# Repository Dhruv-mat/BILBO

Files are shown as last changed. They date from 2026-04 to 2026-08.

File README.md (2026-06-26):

## Overview

This is a custom drone I’ve been working on where I designed pretty much the entire frame from scratch instead of using a standard one.

The idea was to build something that can actually handle onboard compute and not just be a basic RC drone. Initially I was planning to use a Raspberry Pi + OAK-D Lite for perception since it kind of does everything in one go, but that didn’t really work out because of availability and cost, so I had to change things a bit.

Right now the plan is to use a RPI + RPI AI HAT with a normal RGB camera for detection and a TF-Luna LiDAR for distance. It’s definitely not as clean as the OAK-D setup, and I’m not 100% sure how well it’ll perform yet, but it should be good enough if I can get the software side working properly.

A lot of time went into redesigning parts that didn’t work. Especially the motor mounts and arm connectors, some of the earlier versions looked fine in CAD but realistically would’ve probably failed.

The frame uses carbon fiber rods for the arms and landing gear, and 3D printed connectors to hold everything together. It’s way stronger than just printing everything, and also makes it easier to tweak later.

Right now the hardware design is mostly done in CAD, next step is printing and actually seeing if it works the way I think it will.

Right now the hardware design is mostly done in CAD, and next step is printing + assembling + testing.

This new idea of the the RGB camera + a lidar sensor was inspired by this video:
https://youtu.be/Nrzs3dQ9exw?si=6kdqJGR1x-Q6_Brh

Untitledd

Untddditfffledd

---

## Components

- Pixhawk 6C (flight controller)  
- Nvidia Jetsone Nano 2GB
- RPI CAM V2
- TF Luna
- 920KV brushless motors x4  
- 20A / 30A ESCs x4  
- Carbon fiber rods (1.4 cm diameter)  
- 4S LiPo battery
- GPS MODULE
- Telemtry Kit

### Hardware

- M3 screws (10mm, 16mm, 20mm)  
- M4 screws (used for locking arms)  
- M3 female standoffs  
- M4 inserts  
- Nuts and washers  

---

## 3D Printed Parts

You’ll need to print:

- Bottom plate (main frame)  
- Middle plate (for Pixhawk mounting)  
- Top plate (for Raspberry Pi)  
- Arm connectors (holds carbon rods)  
- Motor mounts (final version is reinforced)  
- Landing gear mounts + joints  
- OAK-D Lite holder  
- Raspberry Pi holder  

---

## Assembly

Start with the base plate.



Attach the arm connectors onto the base using M3 screws (I used ~16mm mostly). Make sure these are tight because this is where all the stress goes.



Now insert the carbon fiber rods into the connectors. The fit should already be tight, but I added a side hole so you can pass an M4 screw through and lock it in place.



---

Next is the motor side.
Each arm ends in a motor mount. My first design didn’t work because the alignment was off and there wasn’t enough support, so I switched to a more reinforced design (kind of like a wishbone support).
Attach the motors using standard screws and route the wires back toward the center.



---

Now for the frame stack.
Use M3 standoffs to mount the middle plate above the base. This is where the Pixhawk goes.
Then add another set of standoffs and attach the top plate. The Raspberry Pi sits on top.



---

Landing gear goes on the bottom.
It uses the same carbon rods with angled connectors. I didn’t want it to be completely rigid, so there’s a bit of flexibility to absorb impact when landing.



---

For perception, mount the RGB camera on the front using a custom holder, slightly angled forward.
The TF-Luna LiDAR is mounted alongside it to provide distance measurements.



Untddditfffledd

---

## Electronics Overview

Here is the full system schematic for the drone, including power distribution, flight controller connections, and companion computer setup.


---

## Frame Stress Testing

Also I ran an a basic static stress test on the frame to get a rough idea of how it behaves under load. applied upward forces at the motor mounts to simulate thrust and checked deformation and stress distribution across the arms and connectors. Most of the stress seems to concentrate near the joints and motor mounts which i kinda expected, but nothing looks completely crazy or like it’ll instantly fail. deformation is pretty small overall, so structurally it seems fine for now, although this is still a simplified test and real-world vibrations and impacts aren’t accounted for yet.

WhatsApp Image 2026-04-07 at 09 31 21

WhatsApp Image 2026-04-07 at 09 31 22

---
## Notes

This took way more iteration than expected.
A lot of designs had to be scrapped after realizing they wouldn’t actually work under load. The motor mount especially had to be redone after noticing alignment issues.
Switching to carbon fiber rods instead of fully printed arms made a big difference. It’s way stronger and lighter.
Still a lot left to do but the structure is finally in a place where I can start building it properly.

## Bill of Materials (BOM)

| Part | Quantity | Price (USD) |
|---|---|---|
| Propellers (Pair) | 2 | $2.02 |
|3d prinintg | 1| 35$
| RC Receiver | 1 | $45.78 |
| Telemetry Kit | 1 | $77.11 |
| GPS Module (u-blox) | 1 | $40 |
| ESC (30A BLHeli) | 4 | $38.55 |
| 920KV Brushless Motors | 4 | $31 |
| RPI AI HAT 13TOPS | 1 | $70 |
| Pixhawk 6C | 1 | $360 |
| Rpi Cam V2 | 1 | $18 |
| TF Luna | 1 | $22 |
| LiPo Battery 3S 5200mAh | 1 | $35 |
| Power Distribution Board (PDB) | 1 | $5|
| Holybro PM02 Power Module | 1 | $27|
| Carbon Fiber Rod (25cm) | 1 | $22 |
| Carbon Fiber Tube (Landing Legs) | 1 | $11.7 |
| M3 Female Inserts | 20 | $1 |
| M4 Female Inserts | 20 | $1|
| M3 Screw Set | 1 | $3 |
| M4 Screw Set | 1 | $3 |

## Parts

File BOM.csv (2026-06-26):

Parts | Quantitiy | Total Price USD | Owned
Popellors | 2 | 2.02 | yes
RC Reciver & Transmitter | 1 | 45 | yes
Telemetry Kit | 1 | 77 | yes
GPS module | 1 | 40 | yes
ESC (30A BHeli) | 4 | 38 | yes
920Kv motor | 4 | 31 | no
RPI AI HAT | 1 | 70 | no
Rpi cam V2 | 1 | 18 | no
TF Luna | 1 | 22 | no
Pixhawk 6c | 1 | 360 | yes
LiPO battery 3s 5200mah | 1 | 35 | yes
PDB | 1 | 5 | yes
PMO2 Module | 1 | 27 | no
3d printing | 1 | 35 | no
carbon fiber rod (25cm) | 2 | 22 | no
carbon fiber rod | 1 | 11 | no
M3 Female Insert | 20 | 1 | yes
M4 Female Insert | 20 | 1 | yes
M3 Screws set | 1 | 1 | yes
M4 Screws set | 1 | 1 | yes

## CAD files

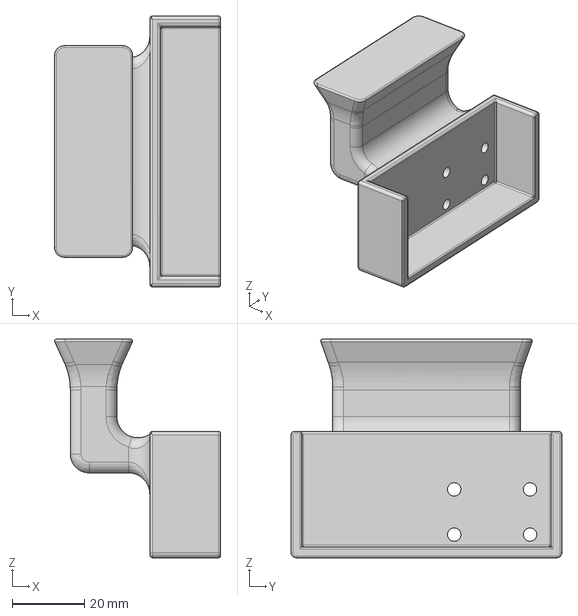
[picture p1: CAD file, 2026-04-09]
BILBO 3D files/sensor holder.step
46.0 x 75.0 x 60.5 mm

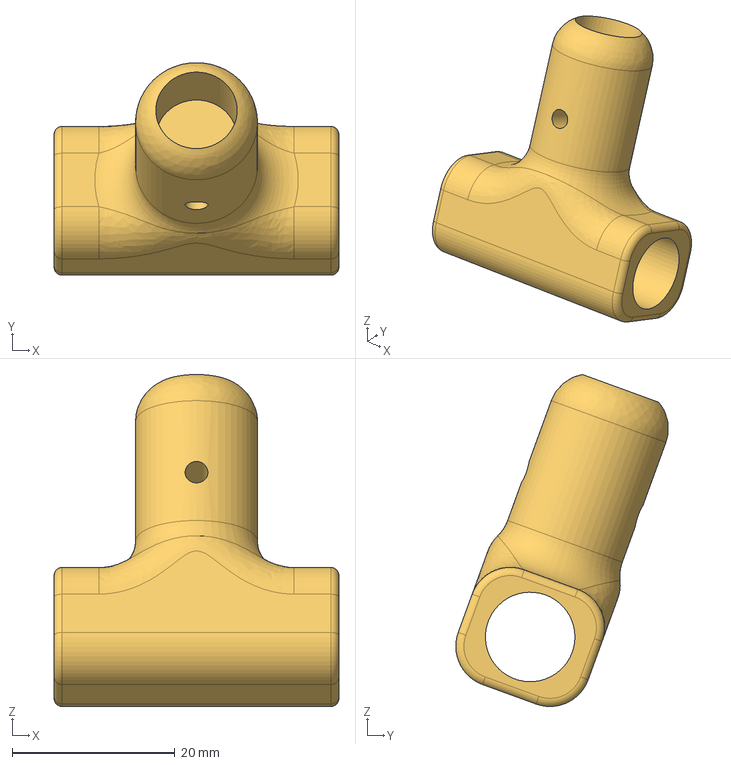
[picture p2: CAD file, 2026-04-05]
BILBO 3D files/BILBO landing gear bracket.step
35.0 x 26.1 x 40.8 mm

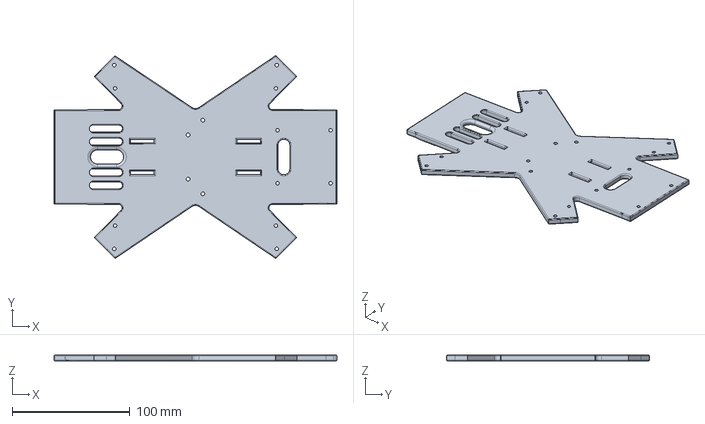
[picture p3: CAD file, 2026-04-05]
BILBO 3D files/BILBO bottom frame.step
240.0 x 172.0 x 5.00 mm

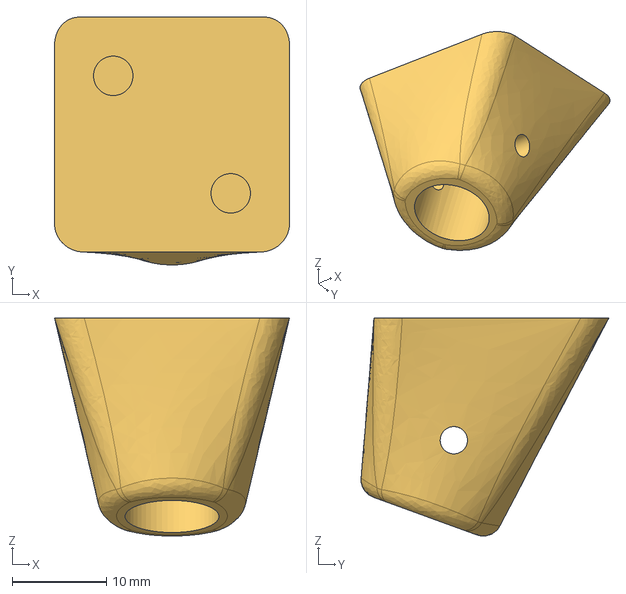
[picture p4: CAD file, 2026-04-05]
BILBO 3D files/BILBO landing gear R.step
25.0 x 26.4 x 23.2 mm

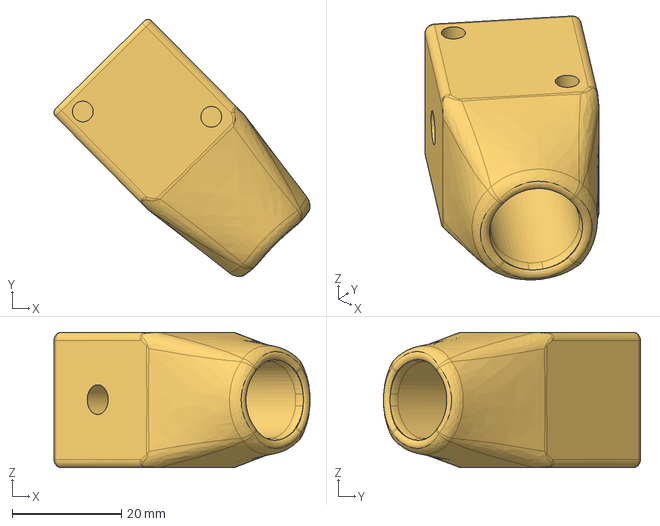
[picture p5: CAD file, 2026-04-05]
BILBO 3D files/BILBO arm connector L.step
47.0 x 47.2 x 24.8 mm

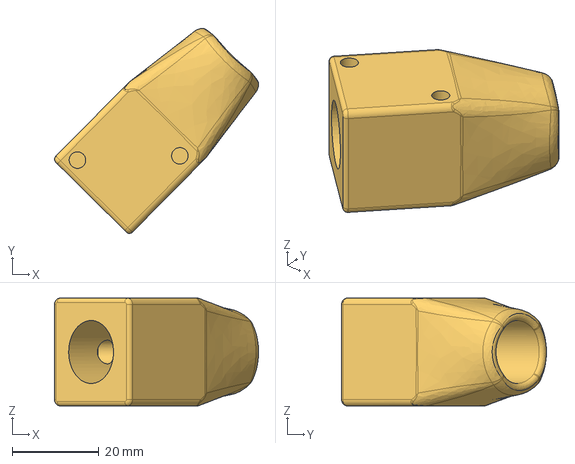
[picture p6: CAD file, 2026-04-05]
BILBO 3D files/BILBO arm connector R.step
47.0 x 47.1 x 24.8 mm

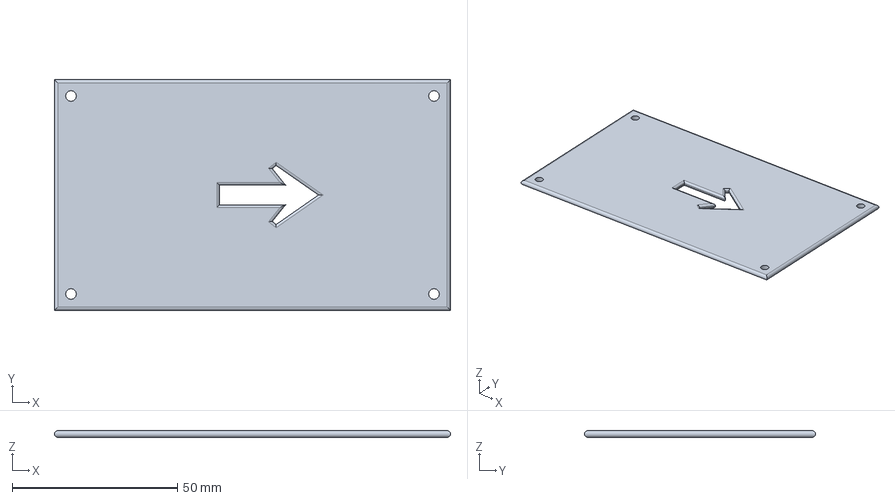
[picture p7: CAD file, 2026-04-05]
BILBO 3D files/BILBO pixhawk mount.step
120.0 x 70.0 x 2.00 mm

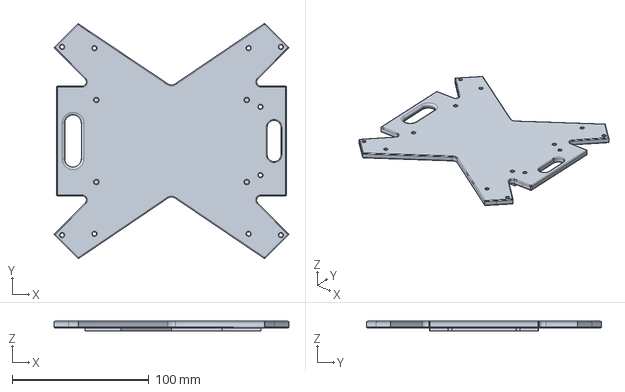
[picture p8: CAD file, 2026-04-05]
BILBO 3D files/BILBO top frame.step
171.8 x 172.0 x 7.00 mm

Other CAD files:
BILBO 3D files/BILBO landing gear L.step
BILBO 3D files/BILBO THE COMPLETE DRONE.f3d

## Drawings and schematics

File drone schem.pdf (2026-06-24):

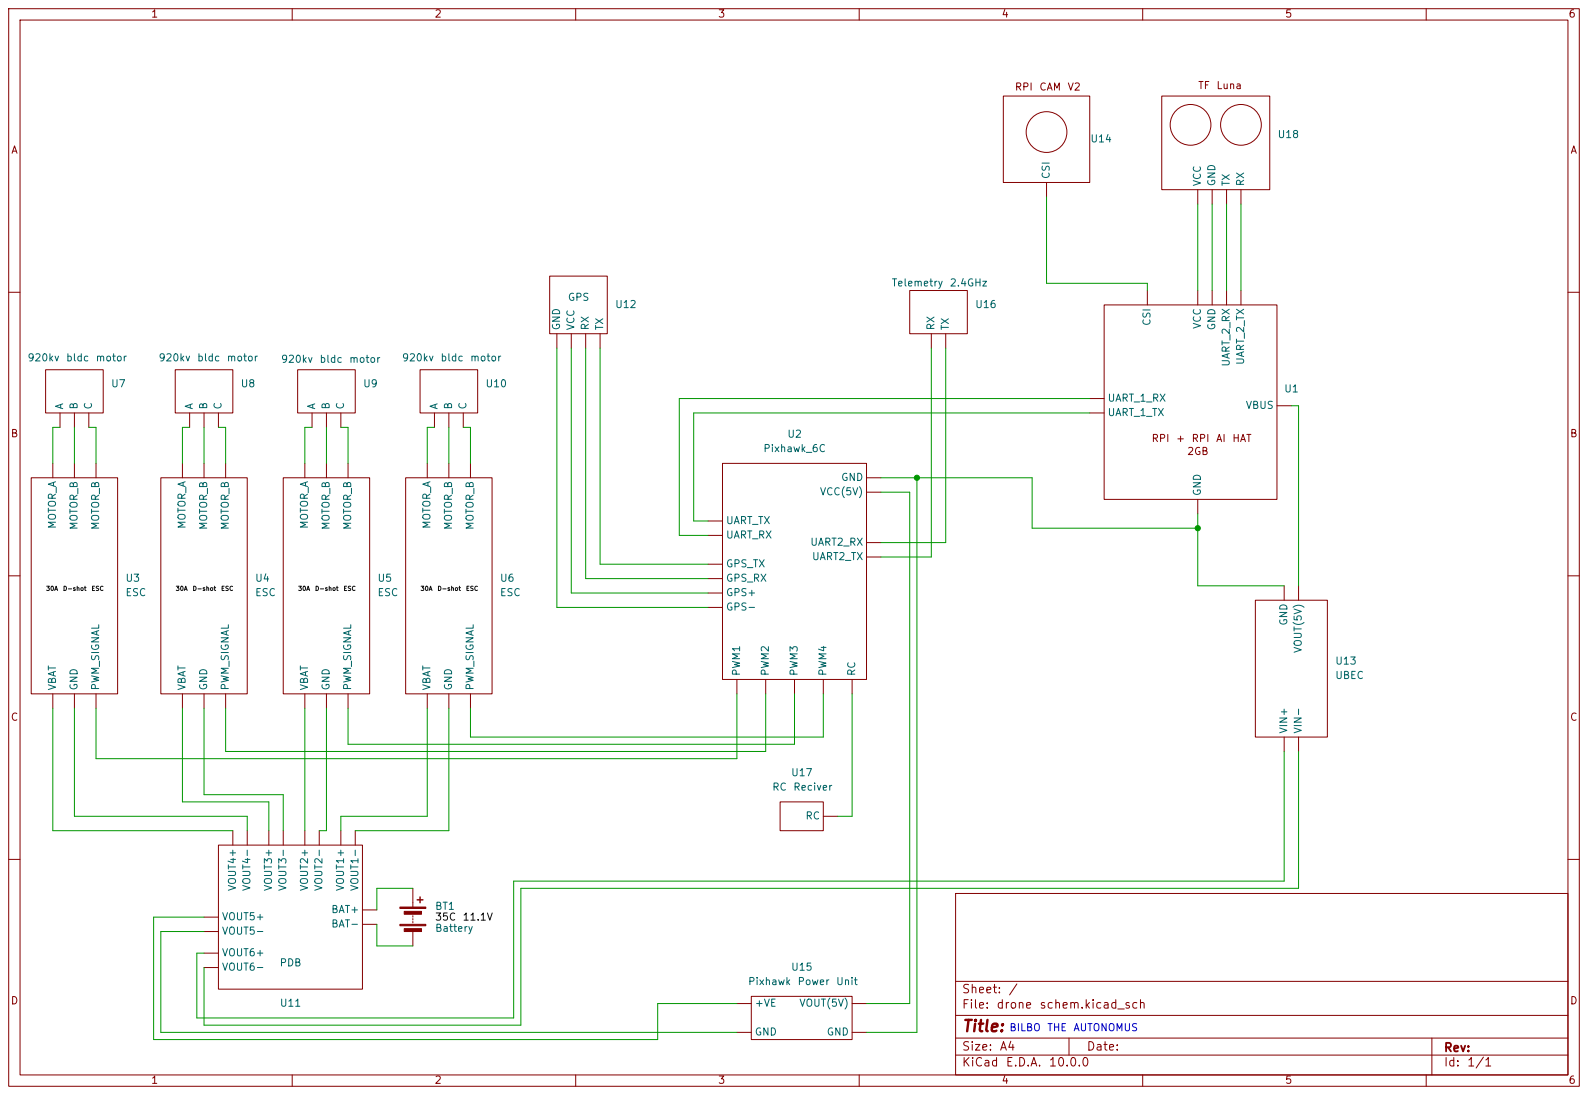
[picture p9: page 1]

VOUT(5V) GND U15 Pixhawk Power Unit RC U17 RC Reciver

Size: A4 | Rev:
KiCad E.D.A. 10.0.0 | Id: 1/1

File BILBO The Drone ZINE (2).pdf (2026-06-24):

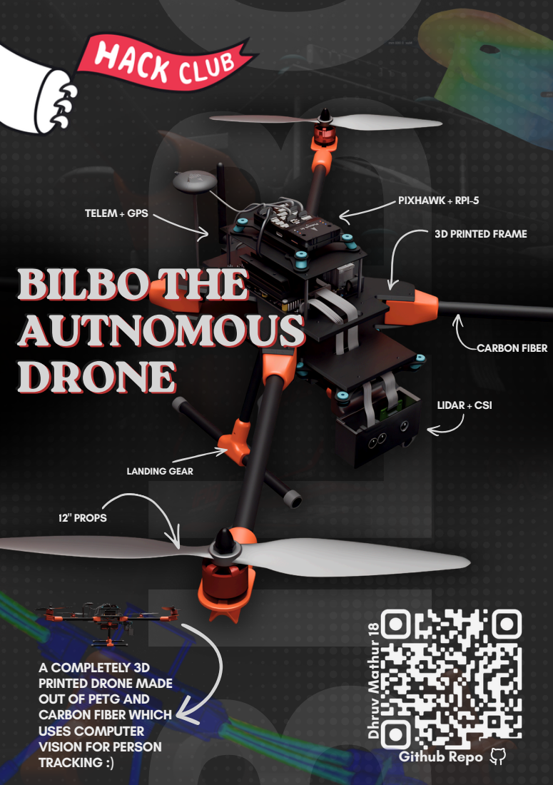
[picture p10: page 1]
BBIILLBBOOTTHHEE AAUUTTNNOOMMOOUUSS DRONE; BILBO THE AUTNOMOUS DRONE; LIDAR + CSI; 3D PRINTED FRAME; Github Repo; PIXHAWK + RPI-5; 12" PROPS; TELEM + GPS; LANDING GEAR; CARBON FIBER

A COMPLETELY 3D
PRINTED DRONE MADE
OUT OF PETG AND
CARBON FIBER WHICH
USES COMPUTER
VISION FOR PERSON
TRACKING :)

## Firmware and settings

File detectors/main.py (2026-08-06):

import csv
import logging
import logging.handlers
import os
import signal
import sys
import time

import config as cfg
import camera
import controller
import drone
import led
import lidar
import tracker
from state import DroneState

_log = logging.getLogger("bilbo")

print("hi bitches")

# okay so this is basically gonna be a function that controls how much freedom the drone will hvae
OFF, YAW_ONLY, FULL = 0 ,1, 2
_ENABLE_NAMES = {OFF: "OFF", YAW_ONLY: "YAW_ONLY", FULL: "FULL"}


state = DroneState.IDLE

reacquire_count = 0
prev_enable = None
engage_armed = False      
confirm_count = 0           

lost_since = None          
last_error_x = 0.0
last_confident_track = None  
track_started = None

search_start = None
search_dir = 1.0           

last_dist = None
last_dist_t = None
jump_count = 0

vision_faults = 0

self_commanded_mode = None 
rtl_requested = False
emergency_since = None
rtl_attempts = 0
land_attempted = False

fault_latch = None
consecutive_faults = 0
_slow_tick = False          
_shutdown = False

_csv_file = None
_csv_writer = None
_last_csv_flush = 0.0
_last_status_log = 0.0



def _setup_logging(): 
    root = logging.getLogger()
    root .setLevel(getattr(logging, cfg.LOG_LEVEL, logging.INFO))

    fmt = logging.Formatter(
        "%(asctime)s %(levelname)-7s %(name)s: %(message)s"
    )

    try:
        os.mkdir(cfg.LOG_DIR,exist_ok = True)
        handler = logging.handlers.RotatingFileHandler(
            os.path.join(cfg.LOG_DIR, "bilbo.log"),
            maxBytes=cfg.LOG_MAX_BYTES,
            backupCount=cfg.LOG_BACKUPS,
        )
        handler.setFormatter(fmt)
        root.addHandler(handler)

    except Exception:

        stream = logging.StreamHandler(sys.stderr)
        stream.setFormatter(fmt)
        root.addHandler(stream)
        root.error("file logging is not working, using stderr", exec_info = True)
        return

    if cfg.DEBUG_CONSOLE:
        stream = logging.StreamHandler(sys.stderr)
        stream.setFormatter(fmt)
        root.addHandler(stream)

CSV_COLUMNS = [
    "t", "state", "enable", "mode", "armed", "alt_m", "link_age_s",
    "rc_age_s", "vision_age_s", "n_persons", "error_x", "error_y",
    "bearing_deg", "dist_cm", "dist_age_s", "yaw_rate", "forward",
    "gate", "tick_s", "fault",

]

#-----the logging pant------------

# all of this is bieng done so i can data log and if needed change the values of that pid loop
def _open_csv():
    global _csv_file, _csv_writer
    try:
        path = os.path.join(cfg.LOG_DIR, "flight-%d.csv" % int(time.time()))
        _csv_file = open(path, "w", newline="", buffering=1024 * 64)
        _csv_writer = csv.writer(_csv_file)
        _csv_writer.writerow(CSV_COLUMNS)
        _log.info("flight log: %s", path)
    except Exception:
        _log.exception("could not open CSV flight log (sad stuffff)")
        _csv_file = None
        _csv_writer = None

def _fmt(value,spec):
    return "" if value is None else spec % value

# alright now we gotta write those csv values in some fancy prtty pretty formats 
def _write_record(record,now):
    global _last_csv_flush
    if _csv_writer is None:
        return


    # also i used chatgpt to generate this really fancy csv file (hope thats cool caue without this formatting im dead)
    try:
        _csv_writer.writerow([
            "%.3f" % now,
            record.get("state", ""),
            record.get("enable", ""),
            record.get("mode") or "",
             "%.2f" % drone.link_age(),
            "%.2f" % drone.rc_age(),
            "%.3f" % record.get("vision_age", float("inf")),
            _fmt(record.get("n_persons"), "%d"),
            "%.1f" % record.get("error_x", 0.0),
            "%.1f" % record.get("error_y", 0.0),
            "%.2f" % record.get("bearing_deg", 0.0),
            _fmt(record.get("distance_cm"), "%d"),
            _fmt(None if last_dist_t is None else distance_age(now), "%.2f"),
            "%.2f" % record.get("yaw_rate", 0.0),
            "%.3f" % record.get("forward", 0.0),
            record.get("gate", ""),
            "%.4f" % record.get("tick_s", 0.0),
            fault_latch or "",
        ])
        # till here heheheh

        if now - _last_csv_flush >= cfg.CSV_FLUSH_INTERVAL_S:
            _csv_file.flush()
            _last_csv_flush = now

    except Exception:
        _log.exception("CSV FILE DID NOT WORRKKK")


def _status(now, message, *args):
    global _last_status_log

    if now - _last_status_log < cfg.STATUS_LOG_INTERVAL_S:
        return
    _last_status_log = now
    _log.info(message, *args)

def _on_signal(signum,_frame):
    global _shutdown
    _shutdown = True
    _log.warning("signal %d received; shutting down", signum)



#----- reseting the PID LOOP PARTTTT---------

def soft_reset(keep_target = False):

    #this part helps setting the pid loops back to zero so no corrrections are pre stored

    global lost_since, reacquire_count, confirm_count, last_error_x
    global last_dist, last_dist_t, jump_count, vision_faults, track_started

    controller.reset()
    if not keep_target:
        tracker.reset()

    lost_since = 0
    reacquire_count = 0
    confirm_count = 0 
    last_error_x = 0
    last_dist = None
    last_dist_t = None
    jump_count = 0
    vision_faults = 0
    track_started = None


#------ really cool lidar logic--------

def update_dist(new_cm, now):
    if new_cm ==None:
        return

    # okay so this part is really sick, what i am trying to do here is making sure the jump in lidar is realistic and not an out of frame error
    if (last_dist is not None and abs(new_cm-last_dist) > cfg.LIDAR_MAX_JUMP_CM):
        jump_count +=1
        if jump_count < cfg.LIDAR_JUMP_CONFIRMS:
            _log.debug("rejecting range jump %d -> %d cm", last_dist, new_cm)
            return

    jump_count = 0
    last_dist = new_cm
    last_dist = now

def distance_or_none(now):

    if last_dist is None or last_dist_t is None:
        return None
    if now - last_dist > cfg.LIDAR_MAX_AGE_S:
        return None
    return last_dist


# this is just something i wanted for the csv column to see how old the lidar is, only used for debugging
def distance_age(now):
    if last_dist_t is None:
        return float("inf")
    return now - last_dist_t


#----- Writing the code to understand the RC funcs----------

def read_enable(now):
    "the 3 channel switching"
    raw = drone.get_channel(cfg.CH_ENABLE)
    if raw is None or drone.rc_age() > cfg.RC_STALE_S:
        return OFF
    if raw < cfg.SWITCH_MID_LOW_US:
        return OFF
    if raw < cfg.SWITCH_MID_HIGH_US:
        return YAW_ONLY
    return FULL

def request_mode(mode, timeout = 1.5, retries = 1):

    global _slow_tick, self_commanded_mode
    _slow_tick = True
    if drone.set_mode(mode, timeout=timeout, retries = retries):
        self_commanded_mode = mode
        return True
    return False



def enter_rtl(reason):
    global state, rtl_requested
    if state == DroneState.RTL:
        return
    _log.warning("RTL(%s)",reason)
    state = DroneState.RTL
    rtl_requested = False


def enter_emegency(reason):
    global state, emergency_since, rtl_attempts, land_attempted
    if state == DroneState.EMERGENCY:
        return
    state = DroneState.EMERGENCY
    emergency_since = None
    rtl_attempts = 0
    land_attempted = False


#------preflight checks and weird ass things--------

def _wait_for(predicate, timeout, interval=0.05, pump=None):
    deadline = time.monotonic() + timeout
    while time.monotonic() < deadline:
        if pump is not None:
            pump()
        try:
            if predicate():
                return True
        except Exception:
            _log.exception("preflight issues happended")


# this one is really important cause it checks if everything is working and fineee before the flight 

def preflight():

    led.init()
    led.selftest()

    if not drone.connect(timeout = 10.0):
        _log.error("Preflight Fail: Mavlink ain't working")
        return False

    try:
        lidar.init()
    except Exception:
        _log.error("Preflight Fail: LiDAR ain't working")
        return False
    
    valid = {'n':0}

    def lidar_healthy():
        if lidar.read_data() is not None:
            valid["n"] += 1
        return valid["n"] >= cfg.LIDAR_HEALTH_FRAMES


    if not _wait_for(lidar_healthy, timeout=3.0):
        _log.error("Preflight Fail:LiDAR gave %d/%d valid frames (%s)",
                   valid["n"], cfg.LIDAR_HEALTH_FRAMES, lidar.health())

        return False

    try:
        width, height = camera.intitalise()
    except Exception:
        _log.exception("Preflight Fail: camera did not start")
        return False

    if not _wait_for(camera.inference_alive, timeout=8.0):
        _log.error("Preflight Fail: no inference output from the IMX500")
        return False

    try:
        tracker.configure(width, height)
    except Exception:
        _log.exception("PREFLIGHT FAIL: camera geometry mismatch")
        return False


    if not _wait_for( lambda: drone.get_channel(cfg.CH_ENABLE) is not None, timeout=5.0,pump=drone.poll):
        _log.error("Preflight Fail: no RC input detected, could never switch to guided")
        return False

    _log.info("preflight OK (lidar %s, camera %s)",
              lidar.health(), camera.health())
    return True


#-----live checks--------

#so basically this part of the code is gonna keep checking if everything is still working after preflight

def run_tick(now, tick_duration):
    global state, prev_enable, engage_armed, confirm_count
    global lost_since, reacquire_count, last_error_x, last_confident_track
    global track_started, vision_faults, fault_latch
    global self_commanded_mode, rtl_requested
    global emergency_since, rtl_attempts, land_attempted
    global search_start, search_dir


    record = {
        "state": state.name, "enable": "?", "mode": None, "armed": False,
        "alt": None, "vision_age": float("inf"), "n_persons": None,
        "error_x": 0.0, "error_y": 0.0, "bearing_deg": 0.0,
        "distance_cm": None, "yaw_rate": 0.0, "forward": 0.0, "gate": "-",
        "tick_s": tick_duration,
    }


    drone.poll()
    drone.send_heartbeat()

    if not drone.link_ok():
        if fault_latch != "link":
            _log.error("MAVLink link lost (age %.1fs)", drone.link_age())
            fault_latch = "link"

        if state in (DroneState.TRACKING, DroneState.SEARCHING):
            soft_reset()
            enter_emergency("link lost")

        drone.reconnect()
        record["gate"] = "link_lost"
        return record

    if fault_latch == "link":
        _log.warning("MAVLink link restored")
        fault_latch = None

    mode = drone.get_mode()
    armed = drone.is_armed()
    alt = drone.get_relative_alt()

    enable = read_enable(now)

    previous_enable = prev_enable
    prev_enable = enable

    record["mode"] = mode
    record["armed"] = armed
    record["alt"] = alt
    record["enable"] = _ENABLE_NAMES.get(enable, "?")

    vision_ts, persons = camera.get_latest()
    vision_age = now - vision_ts

    vision_ok = persons is not None and vision_age <= cfg.VISION_MAX_AGE_S
    record["vision_age"] = vision_age
    record["n_persons"] = None if persons is None else len(persons)

    if state in (DroneState.TRACKING, DroneState.SEARCHING):
        if vision_ok:
            vision_faults = 0
        else:
            vision_faults += 1
            if vision_faults == 1:
                _log.warning(
                    "vision unhealthy: detection age %.2fs, frame age %.2fs, "
                    "persons=%s, health=%s",
                    vision_age, camera.frame_age(),
                    "None" if persons is None else len(persons),
                    camera.health(),
                )
            if vision_faults >= cfg.MAX_VISION_FAULTS:
                soft_reset()
                enter_emergency("vision stalled")


    if mode != "GUIDED":
        if self_commanded_mode is not None and mode == self_commanded_mode:
            record["gate"] = "self_" + mode.lower()
            return record

        if state != DroneState.IDLE:
            _log.info("pilot mode is %s -> IDLE", mode)
            soft_reset()
            state = DroneState.IDLE
        self_commanded_mode = None
        rtl_requested = False
        emergency_since = None
        engage_armed = False
        record["gate"] = "pilot"
        return record

    if enable == OFF:
        engage_armed = False
    elif previous_enable == OFF:
        if not engage_armed:
            _log.info("AI enable edge seen (%s)", _ENABLE_NAMES[enable])
        engage_armed = True


    if enable == OFF and state in (DroneState.TRACKING, DroneState.SEARCHING):
        _log.warning("AI disabled by RC -> READY")
        soft_reset()
        state = DroneState.READY



    if state == DroneState.IDLE:
        soft_reset()
        state = DroneState.READY
        _log.info("READY")
        drone.hover()

    elif state == DroneState.READY:
        drone.hover()

        target = tracker.select(persons) if vision_ok else None
        confirm_count = confirm_count + 1 if target is not None else 0

        alt_ok = alt is not None and alt >= cfg.MIN_TRACK_ALT_M
        target_ok = confirm_count >= cfg.TARGET_CONFIRM_FRAMES

        if engage_armed:
            if not armed:
                _status(now, "engage held: not armed")
            elif not alt_ok:
                _status(now, "engage held: altitude %s < %.1f m",
                        "unknown" if alt is None else "%.1f" % alt,
                        cfg.MIN_TRACK_ALT_M)
            elif not target_ok:
                _status(now, "engage held: target unconfirmed (%d/%d)",
                        confirm_count, cfg.TARGET_CONFIRM_FRAMES)
            else:
                soft_reset(keep_target=True)
                state = DroneState.TRACKING
                track_started = now
                last_confident_track = now
                engage_armed = False
                _log.info("TRACKING engaged (%s)", _ENABLE_NAMES[enable])








    
    




while True:

    ch6 = drone.get_channel(6)
    mode = drone.get_mode()

    if mode != "GUIDED":
        drone.stop()
        state = DroneState.IDLE
        continue

    if state == DroneState.READY:
        if ch6 is not None and ch6 > SWITCH_HIGH:
            print("Tracking enabled")
            led.led_status(effect="solid", color="blue")
            state = DroneState.TRACKING
            continue

    elif state == DroneState.TRACKING:

        persons = camera.get_people()
        target = tracker.select(persons)
        led.led_status(effect="solid", color="green")

        if target is not None:
            lost_frames = 0

        if target is None:
            lost_frames += 1

            if lost_frames >= LOST_FRAME_LIMIT:
                print("starting up searching")
                search_start_time = time.monotonic()
                state = DroneState.SEARCHING
            continue


        if last_good_distance is None:
            lock_center = CAMERA_CENTER
        else:
            lock_center = tracker.get_lock_center(last_good_distance)
        locked, error_x = tracker.is_locked(target, lock_center)

        if abs(error_x) < controller.YAW_DEADBAND:
            
            new_distance = lidar.read_data()
            if new_distance is not None:
                last_good_distance = new_distance

        controller.update(error_x, last_good_distance)

    elif state == DroneState.SEARCHING:

        print("Searching...")
        led.led_status(effect="blink", color="yellow")
        persons = camera.get_people()
        target = tracker.select(persons)

        if target is not None:
            print("Target found!")
            state = DroneState.TRACKING
            continue

        drone.move(
            yaw_rate=SEARCH_YAW_RATE
        )

        if time.monotonic() - search_start_time > SEARCH_TIMEOUT:
            state = DroneState.RTL

    elif state == DroneState.IDLE:
        led.led_status(effect="solid", color="white")
        if mode == "GUIDED":
            print("READY")
            state = DroneState.READY

        continue

    elif state == DroneState.RTL:
        print("RTL")
        led.led_status(effect="solid", color="purple")
        drone.set_mode("RTL")
        continue

    elif state == DroneState.EMERGENCY:
        drone.hover()
        led.led_status(effect="blink", color="red")
        continue

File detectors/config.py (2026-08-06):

import os

MAVLINK_DEVICE = "/dev/serial/by-id/usb-Prolific_Technology_Inc._USB-Serial_Controller_D-if00-port0"
MAVLINK_DEVICE_GLOBS = (
    "/dev/serial/by-id/*FTDI*",
    "usb-Prolific_Technology_Inc._USB-Serial_Controller_D-if00-port0",
)
MAVLINK_BAUD = 57600
LIDAR_DEVICE = "/dev/ttyAMA0"
LIDAR_BAUD = 115200

LED_DEVICE = "/dev/spidev0.0"
LED_COUNT = 25
LED_BRIGHTNESS = 0.3
LED_SPI_KHZ = 800


LOG_DIR = os.path.expanduser("~/bilbo-logs")
LOG_LEVEL = "INFO"
LOG_MAX_BYTES = 8 * 1024 * 1024
LOG_BACKUPS = 5
STATUS_LOG_INTERVAL_S = 0.5
CSV_FLUSH_INTERVAL_S = 1.0


DEBUG_CONSOLE = os.environ.get("BILBO_DEBUG_CONSOLE", "0") == "1"
DEBUG_PREVIEW = os.environ.get("BILBO_DEBUG_PREVIEW", "0") == "1"
DEBUG_DRAW = os.environ.get("BILBO_DEBUG_DRAW", "0") == "1"



TICK_HZ = 15.0
TICK_PERIOD_S = 1.0 / TICK_HZ
MIN_SETPOINT_INTERVAL_S = 1.0 / 20.0

TICK_OVERRUN_LIMIT_S = 0.5
MAX_CONSECUTIVE_FAULTS = 5

HEARTBEAT_TX_INTERVAL_S = 1.0

LINK_TIMEOUT_S = 3.0
RECONNECT_INTERVAL_S = 1.0
RC_STALE_S = 1.0
VISION_MAX_AGE_S = 0.3
MAX_VISION_FAULTS = 30  

IMAGE_WIDTH_PX = 640
IMAGE_HEIGHT_PX = 480
CAMERA_FOV_DEG = 78.0
PIXELS_PER_DEGREE = IMAGE_WIDTH_PX / CAMERA_FOV_DEG

CAMERA_IS_INVERTED = True
LIDAR_MIN_CM = 20
LIDAR_MAX_CM = 800

LIDAR_MIN_STRENGTH = 100
LIDAR_RX_BUFFER_CAP = 512
LIDAR_MAX_AGE_S = 1.0

LIDAR_MAX_JUMP_CM = 150
LIDAR_JUMP_CONFIRMS = 2
LIDAR_HEALTH_FRAMES = 5

LIDAR_HGATE_FRAC = 0.30         
LIDAR_HGATE_MIN_PX = 18         
LIDAR_HGATE_MAX_PX = 90

LIDAR_VGATE_FRAC = 0.25          
LIDAR_VGATE_MIN_PX = 20
LIDAR_VGATE_MAX_PX = 120




LIDAR_BORESIGHT_ROW_PX = IMAGE_HEIGHT_PX // 2
LIDAR_BASELINE_CM = 5.0
LIDAR_OFFSET_SIGN = 1.0
PERSON_CLASS = 0

CONF_THRESHOLD = 0.45

MIN_BOX_AREA_PX = 800

TRACK_GATE_PX = 160.0
TRACK_AREA_RATIO = 2.5





#PID SHITT
YAW_DEADBAND_FRAC = 0.18
YAW_DEADBAND_MIN_PX = 12.0
YAW_DEADBAND_MAX_PX = 55.0

YAW_DEADBAND_PX = 40.0

YAW_PID_OUTPUT_SIGN = -1.0

YAW_KP = 0.10
YAW_KI = 0.0
YAW_KD = 0.0

MAX_YAW_RATE_DEG_S = 50.0

TARGET_DISTANCE_CM = 400.0

DIST_KP = 0.006  
DIST_KI = 0.0
DIST_KD = 0.0
MAX_FORWARD_SPEED_MS = 1.0


FORWARD_SLEW_MS2 = 0.75
FORWARD_ALIGN_LIMIT_DEG = 15.0
MIN_SAFE_DISTANCE_CM = 150.0
BACKOFF_SPEED_MS = 0.4
HARD_MAX_SPEED_MS = 2.0
HARD_MAX_YAW_RATE_DEG_S = 60.0


CH_ENABLE = 8

SWITCH_MID_LOW_US = 1300
SWITCH_MID_HIGH_US = 1700
LOST_TRACK_S = 1.2


TRACK_MAX_MISSES = int(LOST_TRACK_S * TICK_HZ)
REACQUIRE_FRAMES = 3
TARGET_CONFIRM_FRAMES = 3

SEARCH_YAW_RATE_DEG_S = 35.0
SEARCH_TIMEOUT_S = 18.0
MAX_LOST_TRACK_S = 25.0

MAX_TRACK_DURATION_S = 240.0

MIN_TRACK_ALT_M = 2.0
EMERGENCY_HOLD_S = 3.0
MAX_RTL_ATTEMPTS = 2

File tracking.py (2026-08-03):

import argparse
import sys
from functools import lru_cache

import cv2

from picamera2 import MappedArray, Picamera2
from picamera2.devices import IMX500
from picamera2.devices.imx500 import NetworkIntrinsics, postprocess_nanodet_detection

last_detections = []


class Detection:
    def __init__(self, coords, category, conf, metadata):
        self.category = category
        self.conf = conf
        self.box = imx500.convert_inference_coords(coords, metadata, picam2)


def parse_detections(metadata: dict):
    """Parse the output tensor into a number of detected objects, scaled to the ISP output."""
    global last_detections
    bbox_normalization = intrinsics.bbox_normalization
    bbox_order = intrinsics.bbox_order
    threshold = args.threshold
    iou = args.iou
    max_detections = args.max_detections

    np_outputs = imx500.get_outputs(metadata, add_batch=True)
    input_w, input_h = imx500.get_input_size()
    if np_outputs is None:
        return last_detections
    if intrinsics.postprocess == "nanodet":
        boxes, scores, classes = postprocess_nanodet_detection(
            outputs=np_outputs[0], conf=threshold, iou_thres=iou, max_out_dets=max_detections
        )[0]
        from picamera2.devices.imx500.postprocess import scale_boxes

        boxes = scale_boxes(boxes, 1, 1, input_h, input_w, False, False)
    else:
        boxes, scores, classes = np_outputs[0][0], np_outputs[1][0], np_outputs[2][0]
        if bbox_normalization:
            boxes = boxes / input_h

        if bbox_order == "xy":
            boxes = boxes[:, [1, 0, 3, 2]]

    last_detections = [
        Detection(box, category, score, metadata) for box, score, category in zip(boxes, scores, classes) if score > threshold
    ]
    return last_detections


@lru_cache
def get_labels():
    labels = intrinsics.labels

    if intrinsics.ignore_dash_labels:
        labels = [label for label in labels if label and label != "-"]
    return labels


def draw_detections(request, stream="main"):
    """Draw the detections for this request onto the ISP output."""
    detections = last_results
    if detections is None:
        return
    labels = get_labels()
    with MappedArray(request, stream) as m:
        for detection in detections:
            x, y, w, h = detection.box
            label = f"{labels[int(detection.category)]} ({detection.conf:.2f})"

            # Calculate text size and position
            (text_width, text_height), baseline = cv2.getTextSize(label, cv2.FONT_HERSHEY_SIMPLEX, 0.5, 1)
            text_x = x + 5
            text_y = y + 15

            overlay = m.array.copy()


            cv2.rectangle(
                overlay,
                (text_x, text_y - text_height),
                (text_x + text_width, text_y + baseline),
                (255, 255, 255),  
                cv2.FILLED,
            )

            alpha = 0.30
            cv2.addWeighted(overlay, alpha, m.array, 1 - alpha, 0, m.array)


            cv2.putText(m.array, label, (text_x, text_y), cv2.FONT_HERSHEY_SIMPLEX, 0.5, (0, 0, 255), 1)


            cv2.rectangle(m.array, (x, y), (x + w, y + h), (0, 255, 0, 0), thickness=2)

        if intrinsics.preserve_aspect_ratio:
            b_x, b_y, b_w, b_h = imx500.get_roi_scaled(request)
            color = (255, 0, 0)  # red
            cv2.putText(m.array, "ROI", (b_x + 5, b_y + 15), cv2.FONT_HERSHEY_SIMPLEX, 0.5, color, 1)
            cv2.rectangle(m.array, (b_x, b_y), (b_x + b_w, b_y + b_h), (255, 0, 0, 0))


def get_args():
    parser = argparse.ArgumentParser()
    parser.add_argument(
        "--model",
        type=str,
        help="Path of the model",
        default="/usr/share/imx500-models/imx500_network_ssd_mobilenetv2_fpnlite_320x320_pp.rpk",
    )
    parser.add_argument("--fps", type=int, help="Frames per second")
    parser.add_argument("--bbox-normalization", action=argparse.BooleanOptionalAction, help="Normalize bbox")
    parser.add_argument(
        "--bbox-order", choices=["yx", "xy"], default="yx", help="Set bbox order yx -> (y0, x0, y1, x1) xy -> (x0, y0, x1, y1)"
    )
    parser.add_argument("--threshold", type=float, default=0.55, help="Detection threshold")
    parser.add_argument("--iou", type=float, default=0.65, help="Set iou threshold")
    parser.add_argument("--max-detections", type=int, default=10, help="Set max detections")
    parser.add_argument("--ignore-dash-labels", action=argparse.BooleanOptionalAction, help="Remove '-' labels ")
    parser.add_argument("--postprocess", choices=["", "nanodet"], default=None, help="Run post process of type")
    parser.add_argument(
        "-r",
        "--preserve-aspect-ratio",
        action=argparse.BooleanOptionalAction,
        help="preserve the pixel aspect ratio of the input tensor",
    )
    parser.add_argument("--labels", type=str, help="Path to the labels file")
    parser.add_argument("--print-intrinsics", action="store_true", help="Print JSON network_intrinsics then exit")
    return parser.parse_args()


if __name__ == "__main__":
    args = get_args()

    # This must be called before instantiation of Picamera2
    imx500 = IMX500(args.model)
    intrinsics = imx500.network_intrinsics
    if not intrinsics:
        intrinsics = NetworkIntrinsics()
        intrinsics.task = "object detection"
    elif intrinsics.task != "object detection":
        print("Network is not an object detection task", file=sys.stderr)
        exit()

    # Override intrinsics from args
    for key, value in vars(args).items():
        if key == 'labels' and value is not None:
            with open(value, 'r') as f:
                intrinsics.labels = f.read().splitlines()
        elif hasattr(intrinsics, key) and value is not None:
            setattr(intrinsics, key, value)

    # Defaults
    if intrinsics.labels is None:
        with open("assets/coco_labels.txt", "r") as f:
            intrinsics.labels = f.read().splitlines()
    intrinsics.update_with_defaults()

    if args.print_intrinsics:
        print(intrinsics)
        exit()

    picam2 = Picamera2(imx500.camera_num)
    config = picam2.create_preview_configuration(controls={"FrameRate": intrinsics.inference_rate}, buffer_count=12)

    imx500.show_network_fw_progress_bar()
    picam2.start(config, show_preview=True)

    if intrinsics.preserve_aspect_ratio:
        imx500.set_auto_aspect_ratio()

    last_results = None
    picam2.pre_callback = draw_detections
    while True:
        last_results = parse_detections(picam2.capture_metadata())

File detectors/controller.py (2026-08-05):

import drone
from simple_pid import PID
import time

MAX_YAW_RATE =20
YAW_DEADBAND = 50
TARGET_DISTANCE = 160  
MAX_YAW_RATE = 15    
MAX_FORWARD_SPEED = 2

yaw_pid = PID(
    Kp=0.10,
    Ki=0.00,
    Kd=0.00,
    setpoint=0
)

distance_pid = PID(
    Kp=0.02,
    Ki=0.00,
    Kd=0.00,
    setpoint=TARGET_DISTANCE
)

yaw_pid.output_limits = (-MAX_YAW_RATE, MAX_YAW_RATE)
distance_pid.output_limits = (-MAX_FORWARD_SPEED, MAX_FORWARD_SPEED)

def update(error_x, distance):

    if abs(error_x) < YAW_DEADBAND:
        yaw_rate = 0
    else:
        yaw_rate = yaw_pid(error_x)
    print(f"Distance: {distance}")

    if distance is None:
        pid_output = 0
        forward_velocity = 0

    else:
        pid_output = distance_pid(distance)
        forward_velocity = -pid_output

    print("------------------------")
    print(f"Time             : {time.monotonic():.3f}")
    print(f"Error X          : {error_x}")
    print(f"Distance         : {distance}")
    print(f"Yaw Rate         : {yaw_rate}")
    print(f"PID Output       : {pid_output}")
    print(f"Forward Velocity : {forward_velocity}")
    
    drone.move(
    forward_speed=forward_velocity,
    yaw_rate=yaw_rate
)

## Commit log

2026-03-21 Enhance README with comprehensive project details
    Expanded the README to include detailed sections on overview, components, 3D printed parts, assembly instructions, current status, and notes on design iterations.
2026-03-21 Enhance README with assembly steps and images
    Added detailed assembly instructions and images for the project.
2026-03-21 Update assembly instructions and notes in README
    Removed outdated information and added details about the assembly process, including motor mounts and landing gear.
2026-03-21 Clarify redesign challenges in README
    Updated wording for clarity regarding motor mounts and arm connectors.
2026-03-21 fixed images folder (removed submodule)
    [DRONE v42.stl, DRONE_FusionFile.f3d, drone arm attachment 2.stl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]
2026-03-21 Add schematic image for drone electronics overview
2026-03-22 Add Bill of Materials section to README
    Added a Bill of Materials (BOM) section with parts, quantities, and prices.
2026-04-10 Revise README for hardware updates and stress testing
    Updated the README to reflect changes in hardware components and design approach, including the switch from OAK-D Lite to Jetson Nano and added details about stress testing.
2026-06-20 gihub organisation
    [BOM.csv]
2026-06-20 more github orgasnisation
    [BILBO THE COMPLETE DRONE.f3d, DRONE v42.stl, drone arm attachment 2.stl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]
2026-06-24 Replace Jetson Nano with Coral TPU in BOM
    [BOM.csv]
2026-06-26 Modify BOM quantities and add new item
    Updated quantities for ESC (30A BHeli) and RPI AI HAT, and added 3d printing item.
    [BOM.csv]
2026-07-26 test case changes
2026-08-01 Pid controler and a lil bit of drone kit
2026-08-05 led provisions added...yay
2026-08-05 adding led control to drone motor control
2026-08-06 Adding fail safes and preflight cheacks
    [camera.py, config.py, led.py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]
2026-08-06 changes to lidar stuff added a health function
